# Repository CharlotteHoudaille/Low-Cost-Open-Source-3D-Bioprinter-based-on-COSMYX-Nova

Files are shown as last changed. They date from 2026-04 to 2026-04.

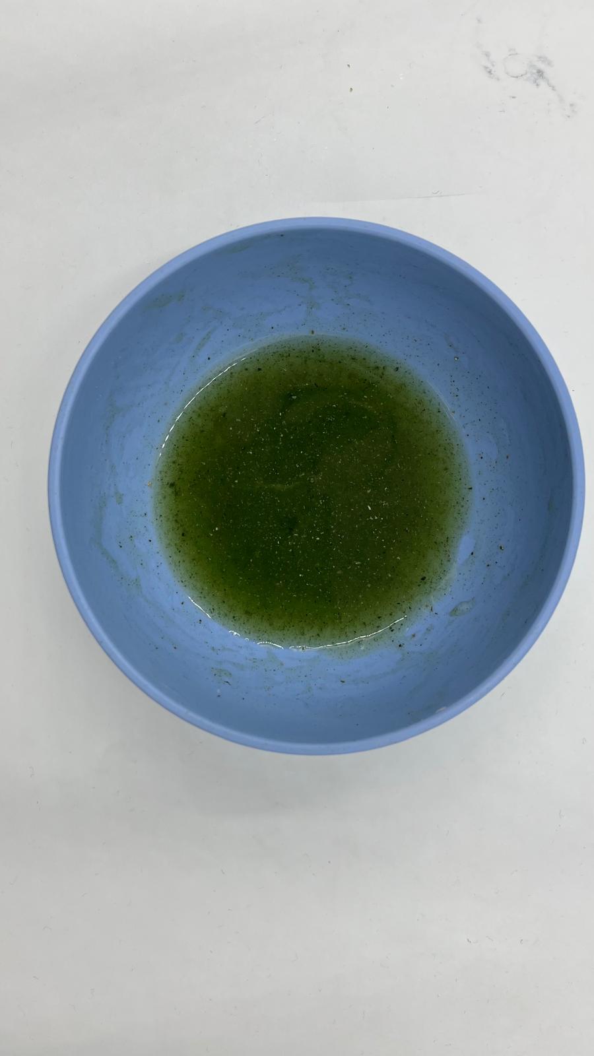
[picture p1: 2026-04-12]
test_hydrogels/spirulina/spiruina_preparation.jpeg

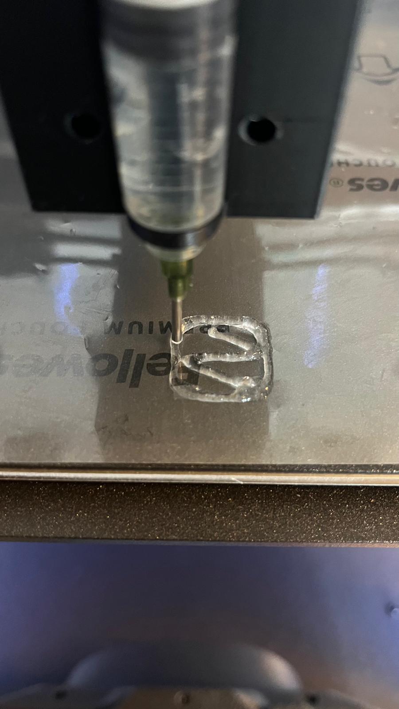
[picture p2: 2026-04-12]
test_hydrogels/cmc_alginate/print_tests/print2.jpeg

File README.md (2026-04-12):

# Low-Cost Open-Source 3D Bioprinter based on COSMYX Nova

## Project Overview
This project explores the transformation of a conventional **FDM 3D printer (COSMYX Nova)** into a **low-cost syringe-based bioprinter** capable of printing hydrogels and bio-derived materials.

The objective is to make bioprinting technologies more accessible to **open-source, DIY, and low-budget research communities**.

The project covers:
- custom hardware modification
- firmware and machine debugging
- slicer calibration
- hydrogel testing
- biological material experiments
- future hardware and research improvements

---

## Project Goals
- convert a standard 3D printer into a syringe-based bioprinter
- print extrusion-based hydrogels
- test bio-derived materials such as spirulina
- document a reproducible low-cost setup

---

## Repository Structure

### `/hardware`
Contains all mechanical documentation related to the custom print head:
- CAD files
- STL / fabrication files
- assembly guide
- hardware description
- print head architecture

---

### `/firmware`
Contains all software and machine configuration documentation:
- OctoPrint / Klipper setup
- firmware modifications
- temperature override
- bed mesh correction
- SD card reflashing and debugging notes

---

### `/slicer`
Contains the slicing workflow and calibration files:
- Orca Slicer project file (`.3mf`)
- calibration parameters
- printing methodology
- key parameters for hydrogel extrusion

---

### `/test_hydrogels`
Contains all hydrogel formulations and print tests:
- CMC–alginate recipe and results
- spirulina hydrogel recipe and results
- photos and videos of gels and printed structures
- experimental observations

---

## System Summary
The original thermoplastic extruder was replaced by a **custom syringe extrusion system**.

The existing stepper motor drives:
- a gear train
- a vertical screw mechanism
- a syringe holder / piston pusher

This allows controlled extrusion of high-viscosity hydrogels.

---

## Main Experimental Results
The project successfully demonstrated:
- 2D hydrogel printing
- 3D hollow and filled structures
- proof-of-concept extrusion of spirulina-based material
- iterative firmware and slicer calibration

This work does **not yet constitute a full viability study**, but demonstrates the feasibility of low-cost hydrogel bioprinting.

---

## Future Contributions
Potential future developments include:
- improved lead screw mechanism
- stronger syringe guidance system
- better linear alignment
- enhanced firmware robustness
- plastic upcycling / filament recycling project

---

## Author
Charlotte Houdaille  
CreaTech IFT – ESILV# Low-Cost-Open-Source-3D-Bioprinter-based-on-COSMYX-Nova
## Project Overview
This project explores the transformation of a conventional FDM 3D printer (COSMYX Nova) into a low-cost extrusion-based bioprinter capable of printing hydrogels and bio-derived materials. The objective is to make bioprinting technologies accessible to open-source and DIY research communities.

This work includes:
- hardware modification of the printer
- firmware and software debugging
- slicer calibration
- test hydrogel formulation
- biological material experiment
- hardware improvements

---

## Project Goals
- Transform a standard 3D printer into a syringe-based bioprinter
- Print extrusion-based hydrogels
- Test biologically derived materials such as spirulina
- Document a reproducible low-cost setup

---

## System Architecture

### Hardware
The original FDM extruder was replaced by a **custom syringe extrusion system**.

The printer’s original stepper motor drives:
- a gear train
- a central screw
- a moving white carriage (syringe holder to control extrusion flow)

### Main Components
- COSMYX Nova 3D printer
- custom 3D-printed syringe holder
- custom 3D-printed gear mechanism
- vertical screw
- syringe + nozzle

---

## Hardware Documentation

### Bill of Materials (BOM)
- COSMYX Nova printer
- stepper motor (existing printer motor)
- 3D-printed gears
- screw
- syringe holder
- syringe piston pusher
- 20 mL syringe
- nozzle
- screws and mounting parts
- Raspberry Pi
- SD card

Detailed BOM available in `/hardware/BOM_hardware.md`
The 3D files for the different parts of the printhead can be found in the hardware branch.
Please note that the full assembly also requires M8 nuts and bolts, along with two aluminum support rods (8.30 mm diameter) with lengths of 106.5 mm and 74.50 mm, which must be inserted into the syringeholder part.

---

## Assembly Instructions
1. Remove the original thermoplastic extruder
2. Install the syringe holder on the carriage
3. Mount the gear system
4. Connect the stepper motor to the gears
5. Install the threaded rod
6. Attach the piston pusher mechanism
7. Insert the syringe
8. Test vertical movement
9. Validate extrusion motion

Detailed assembly guide available in `/hardware/assembly_guide.md`

---

## Software / Firmware

### Firmware Stack
- OctoPrint
- Klipper
- Raspberry Pi

### Debugging Performed
During the project, several firmware issues had to be resolved:
- emergency stop causing display failure
- SD card reflashing
- Raspberry Pi software update
- nozzle and bed unwanted heating
- bed mesh collision issues
- chassis collision correction

Configuration notes available in `/firmware`

---

## Slicer Calibration
The project required adapting standard FDM slicing workflows to hydrogel extrusion.

Software used:
- **Orca Slicer**

Main parameters calibrated:
- layer height
- extrusion flow
- infill density
- speed
- line width
- temperature disabled
- multi-layer stacking

Calibration tests included:
- 2D heart shape
- hollow cube
- filled cube

Files and notes available in `/slicer`

---

## Materials / Hydrogel Formulations

### CMC + Alginate Hydrogel
- 40 mL distilled water
- 2 g alginate
- 2 g carboxymethylcellulose

Used for calibration and structural print tests.

---

### Spirulina Hydrogel
- 40 mL distilled water
- 5 g spirulina
- 2 g alginate
- 2 g glycerol

Crosslinked in calcium chloride bath.

Detailed formulations available in `/materials`

---

## Experimental Results

### Calibration
Several iterative print-calibration loops were carried out:
1. modify Orca Slicer parameters
2. test print
3. observe results
4. repeat

This allowed progressive improvement of:
- line consistency
- layer stacking
- 3D print fidelity

---

### Biological Material Test
A spirulina-based hydrogel was successfully extruded as a proof of concept of **bio-derived material printing**.

This stage focused on:
- extrusion feasibility
- shape retention
- hydrogel stability

This is **not yet a proof of biological viability study**.

---

## Applied Research
Inspired by the *LivingLoom* paper (CHI 2025), a methodology based on:
- hydrogel formulation
- crosslinking bath
- washing phase
- growth observation over time

was partially replicated to explore post-fabrication biological development.

---

## Images / Demo
Project photos, screenshots and demo results are available in:

- `/images/demo_photos`
- `/images/calibration_tests`
- `/images/spirulina_tests`
- `/videos`

---

## Future Contributions
- improved lead screw mechanism
- stronger syringe holder
- better linear guidance
- improved firmware robustness
- integration on Prusa platform
- plastic upcycling line (Ghana project)

---

## References
See `/docs/references.md`

---

## Author
Charlotte Houdaille  
CreaTech – ESILV

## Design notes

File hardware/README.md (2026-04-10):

# Print Head / Extrusion System

The design of the extrusion head was initially inspired by previous work from **Cordova et al. – The Enderstruder**.

Unlike many commercial bioprinters that rely on pneumatic pumping systems, this project uses a **piston-based extrusion mechanism**. Pneumatic systems require very precise pressure control and can make bio-ink retention during printing more difficult.

For this reason, we chose a **mechanical piston extrusion system** driven by the existing motor of the COSMYX Nova printer.

The system includes a **1:4 gear ratio transmission**, designed to increase torque and allow the extrusion of **high-viscosity hydrogels and bio-inks**.

The printer’s original stepper motor drives the gear train, which rotates a central screw mechanism. This causes the piston carriage to move vertically and apply controlled pressure to the syringe plunger.

Initial iterations were based on the original vertical design proposed in the Enderstruder model.

However, due to the specific geometric constraints of the **COSMYX Nova architecture**, a complete redesign of the print head was required.

Several design iterations were carried out in order to optimize:
- alignment
- rigidity
- syringe stability
- collision avoidance with the frame

The final version corresponds to the design used for the calibration and hydrogel printing experiments.

---

## CAD Files

All 3D fabrication files are available in:

`hardware/cad_files/`

This folder includes the different mechanical parts of the extrusion system, such as:

- core structure
- syringe holder
- piston
- bevel gears
- herringbone gears
- sensor holder

The complete assembly also requires:
- M8 screws and nuts
- two aluminium support rods
- syringe and nozzle

---

## Assembly Guide

A detailed assembly and disassembly guide is available in:

`hardware/Montage Guide.pdf`

This document explains how to:
- remove the original FDM extruder
- install the custom syringe extrusion system
- mount the gears and piston
- insert the support rods
- assemble the syringe holder

---

## Installation Notes

Before installing the extrusion head, the original FDM extruder must be fully removed in order to free the support plate.

Once the original extruder is removed, follow the **Montage Guide.pdf** for the complete assembly process.

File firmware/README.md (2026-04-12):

# Firmware and Machine Configuration

This folder documents the firmware modifications performed on the COSMYX bioprinter.

The printer runs on **OctoPrint + Klipper**.

A significant part of the project involved debugging and modifying the machine configuration in order to adapt the printer to the custom syringe extrusion system.

---

## Main Firmware Modifications

### 1. Temperature Control Override
For hydrogel printing, nozzle and bed heating had to be completely disabled.

The original printer firmware was still forcing temperature control even when disabled in Orca Slicer.

To solve this, several temperature-related parameters were manually modified in the Klipper configuration files.

Key changes include:
- nozzle temperature set to 0
- bed temperature set to 0
- home preheat variables disabled
- minimum extrusion temperature reduced

See:
- `temperature_override_parameters.png`

---

### 2. Extruder Parameters
The custom syringe extrusion system required modifications to the default extruder settings.

Main modified parameters include:
- rotation distance
- nozzle diameter
- minimum extrusion temperature
- max extrusion cross-section

These changes were necessary to adapt the printer to **hydrogel syringe extrusion instead of thermoplastic filament extrusion**.

See:
- `extruder_configuration_parameters.png`

---

### 3. Bed Mesh Correction
Because the custom syringe extruder is significantly larger than the original FDM extruder, the default bed mesh area was causing collisions with the frame.

The `[bed_mesh]` parameters were modified in order to reduce the probing zone and avoid the custom print head hitting the chassis.

Main modified parameters include:
- mesh_min
- mesh_max
- horizontal_move_z
- probe_count

See:
- `bed_mesh_parameters.png`

---

## Configuration File Location
All these parameters were modified through:

**OctoPrint → Klipper Configuration → Config Files**

See:
- `klipper_config_files_overview.png`

---

## Major Debugging Incident
During the calibration phase, a major issue occurred after an emergency stop had been triggered earlier in January.

This caused the printer screen to stop displaying anything.

To recover the system, the following steps were performed:
- opening the printer electronics
- locating the Raspberry Pi
- removing the SD card
- reflashing the SD card with a fresh image
- reinstalling OctoPrint / Klipper configuration

This debugging phase was essential to restore the machine and continue the calibration work.

---

## Important Note
These firmware modifications are **specific to the custom syringe extrusion system** and should not be used for standard FDM printing without verification.

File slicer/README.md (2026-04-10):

# Slicer Documentation

This folder contains the slicing setup used during the hydrogel calibration and 3D printing tests.

The main project file is:

`cmc_alginate_calibration.3mf`

This file already contains all the calibrated Orca Slicer parameters used for the **CMC–alginate hydrogel**.

The full hydrogel recipe can be found in the **Hydrogels** section of the main repository documentation.

---

## Important Note

All the slicing parameters saved in the `.3mf` file were specifically optimized for the **CMC–alginate hydrogel formulation**.

These settings are **not intended for standard thermoplastic printing**.

The calibration was developed for:
- syringe extrusion
- high-viscosity hydrogel flow
- stable layer stacking
- filled 3D structures

---

## Key Parameters

Some of the most important parameters adjusted during the calibration process include:

### Layer Height
Example:
- layer height: **1 mm**
- initial layer height: **1 mm**

A larger layer height was required to match the extrusion flow of the hydrogel.

---

### Line Width
Example:
- default line width: **1.2 mm**
- outer wall: **1.2 mm**
- infill: **1.2 mm**

The line width was increased to improve:
- line continuity
- wall stability
- infill cohesion

---

### Infill
The infill settings were one of the most critical parameters to tune.

Several iterations were performed to obtain:
- filled cubes
- stable internal structure
- good contact between walls and infill

---

### Speed
Printing speed was progressively reduced in order to improve hydrogel deposition and avoid flow inconsistencies.

---

### Temperature
Nozzle and bed heating were disabled for hydrogel printing.

---

## Calibration Workflow
The calibration followed an iterative loop:

1. modify one parameter
2. print test geometry
3. observe result
4. adjust settings
5. repeat

This was repeated multiple times on:
- 2D heart
- hollow cube
- filled cube

---

## Recommendation
For any new hydrogel formulation, the following parameters should be adjusted first:

- layer height
- line width
- print speed
- infill density
- flow consistency

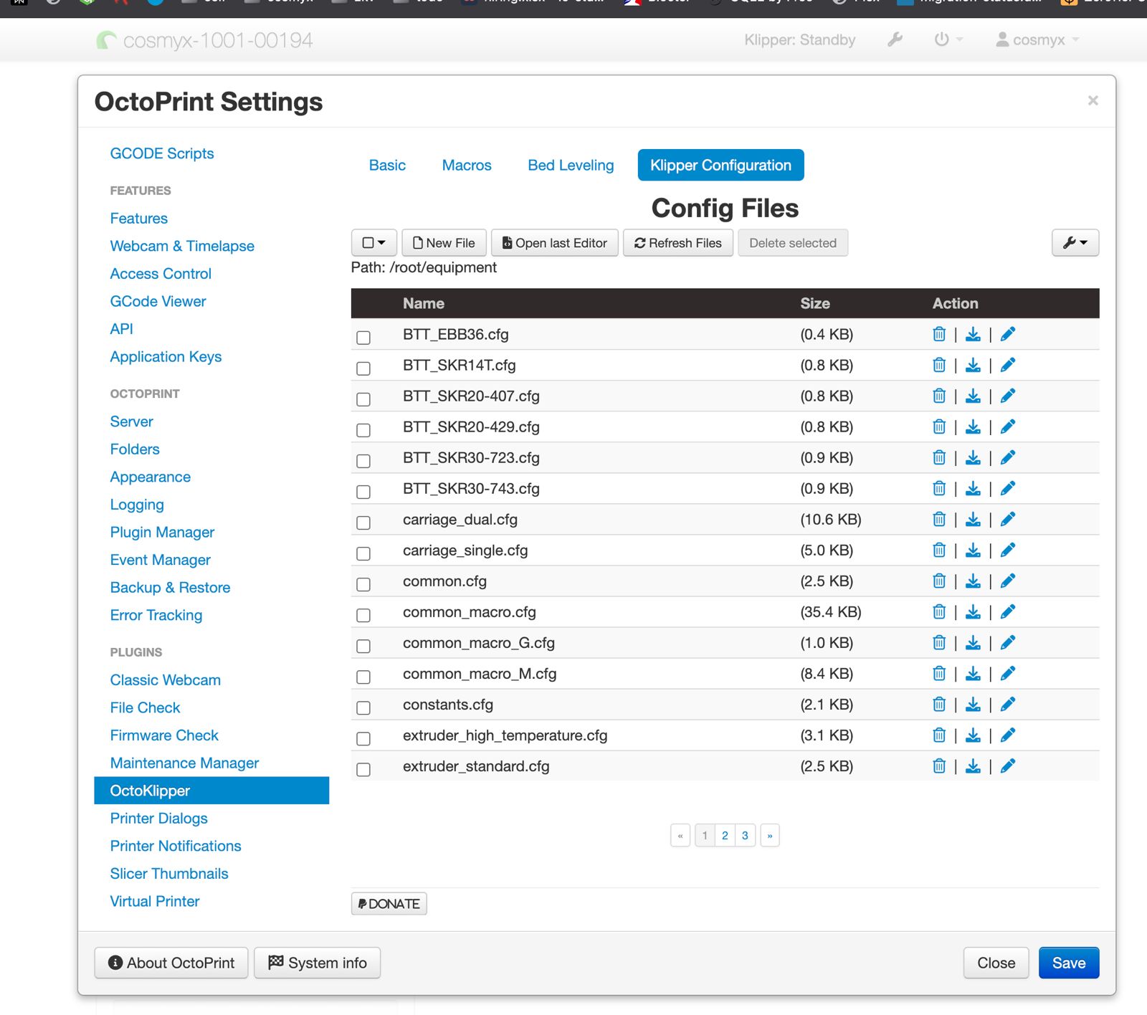
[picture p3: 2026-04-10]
firmware/screenshots/ klipper_config_files_overview.png

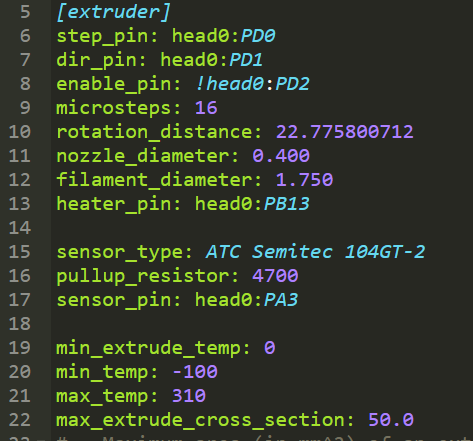
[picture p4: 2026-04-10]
firmware/screenshots/extruder_configuration_parameters.png

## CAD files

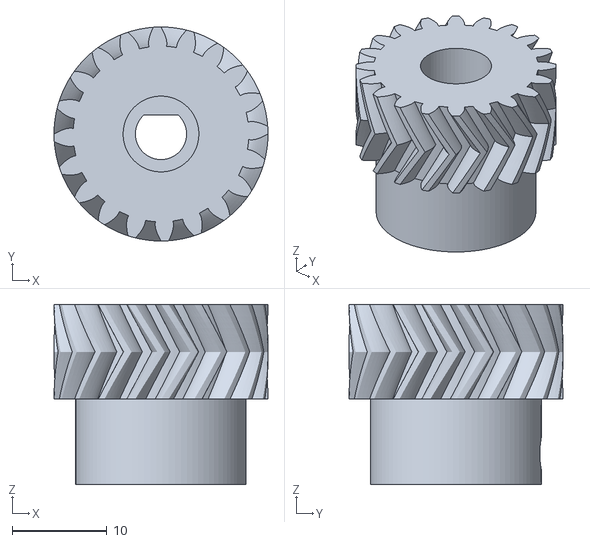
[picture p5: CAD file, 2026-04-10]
hardware/cad_files/Small herringbone gear.stl
22.6 x 22.6 x 19.0

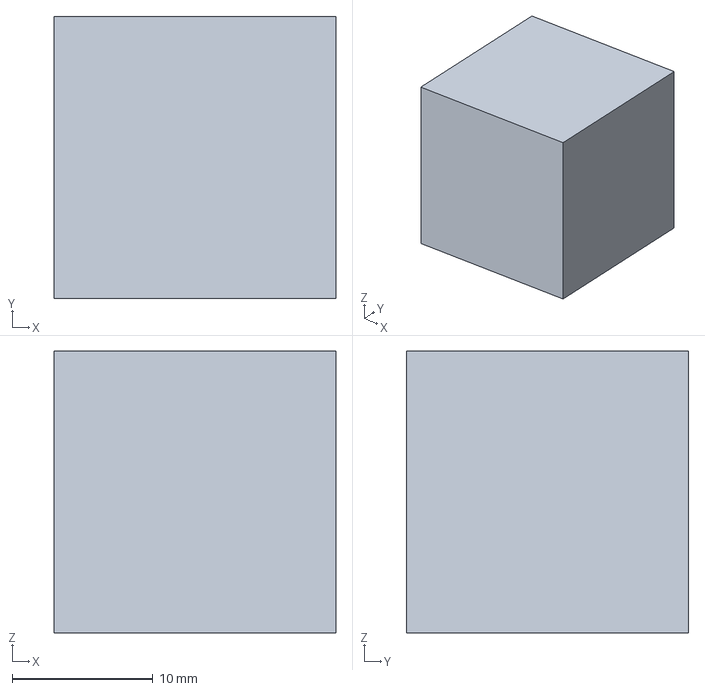
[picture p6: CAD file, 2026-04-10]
slicer/cmc_alginate_calibration.3mf
20.0 x 20.0 x 20.0 mm

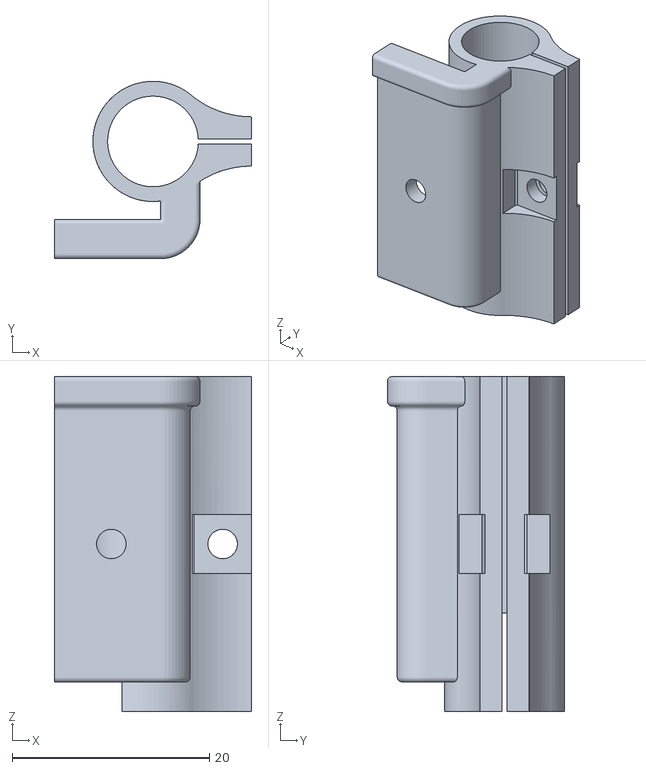
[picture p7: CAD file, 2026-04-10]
hardware/cad_files/sensor.stl
20.0 x 18.0 x 34.0

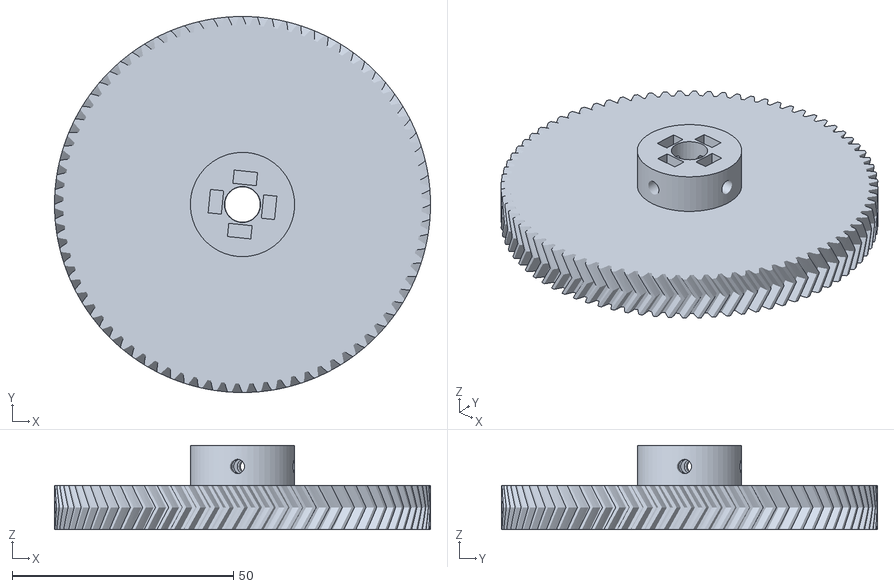
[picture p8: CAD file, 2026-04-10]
hardware/cad_files/Large herringbone gear.stl
84.9 x 84.9 x 19.0

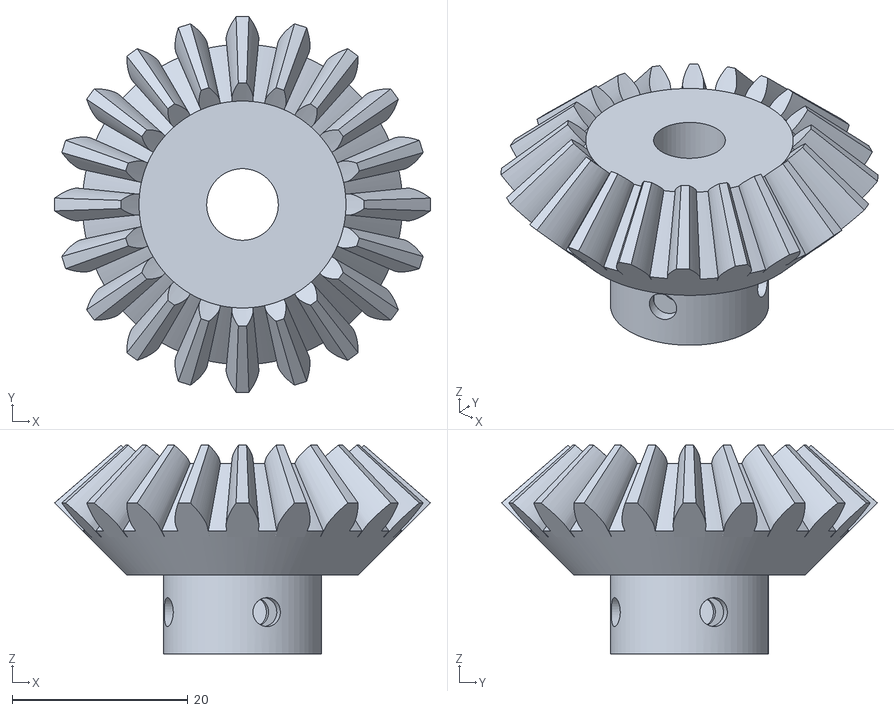
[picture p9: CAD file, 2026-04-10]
hardware/cad_files/bevel gear_29.stl
42.8 x 42.8 x 23.8

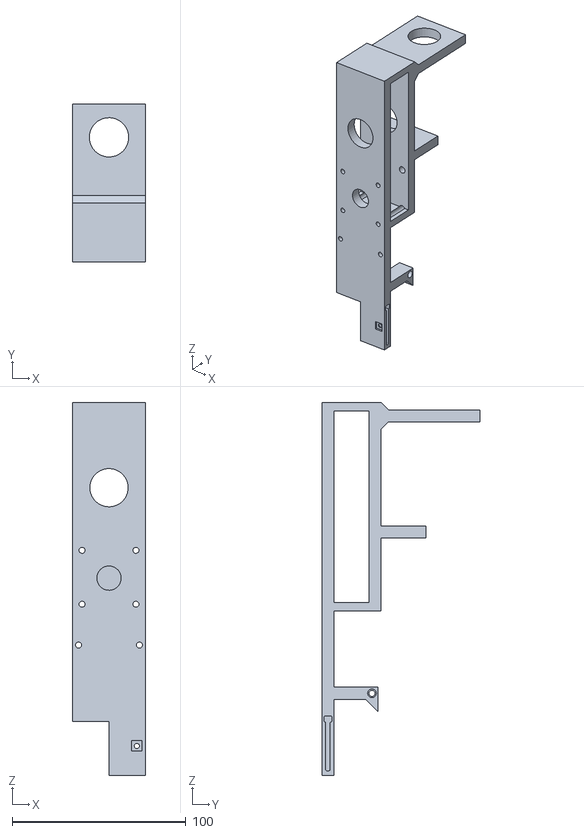
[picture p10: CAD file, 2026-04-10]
hardware/cad_files/core.stl
42.0 x 91.0 x 214.5

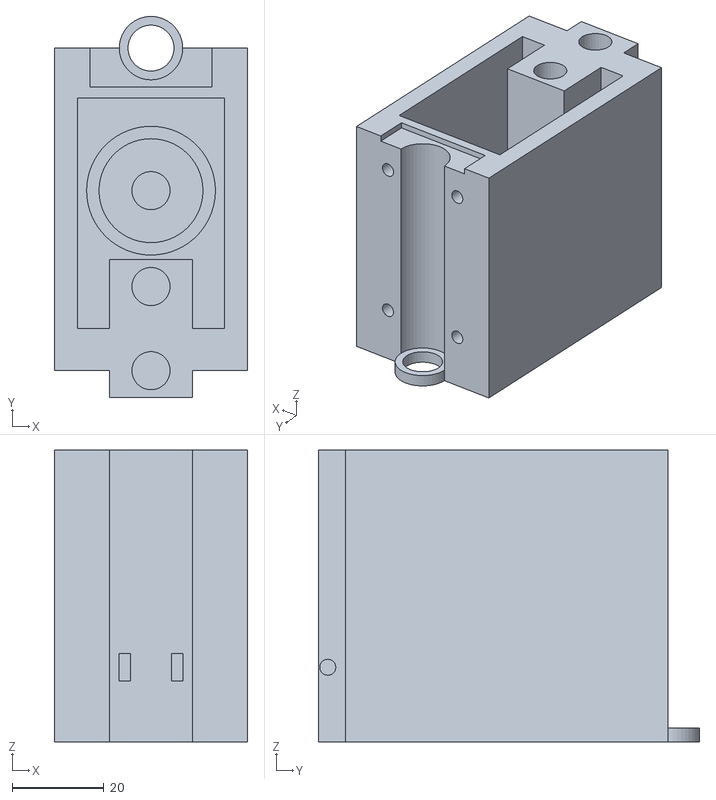
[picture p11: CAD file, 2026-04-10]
hardware/cad_files/syringeholder.stl
42.0 x 82.9 x 63.5

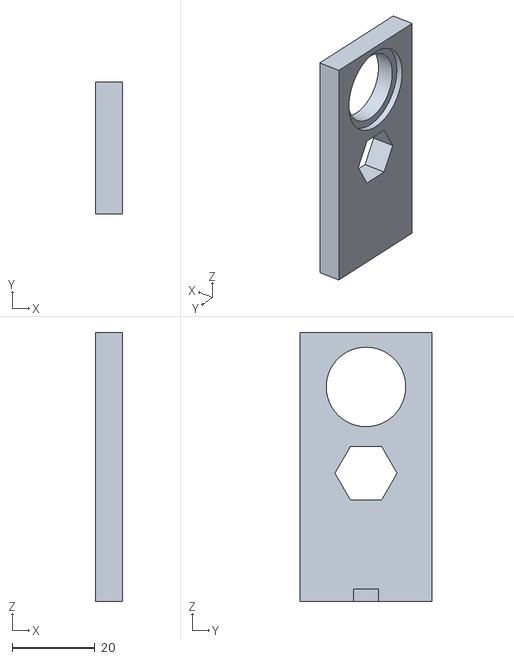
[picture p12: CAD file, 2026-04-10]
hardware/cad_files/Piston.stl
6.50 x 32.0 x 65.0

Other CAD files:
hardware/cad_files/bevel gear_28.stl

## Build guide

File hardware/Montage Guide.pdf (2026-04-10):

Guide de Montage/démontage tête de bio impression Cosmyx Nova

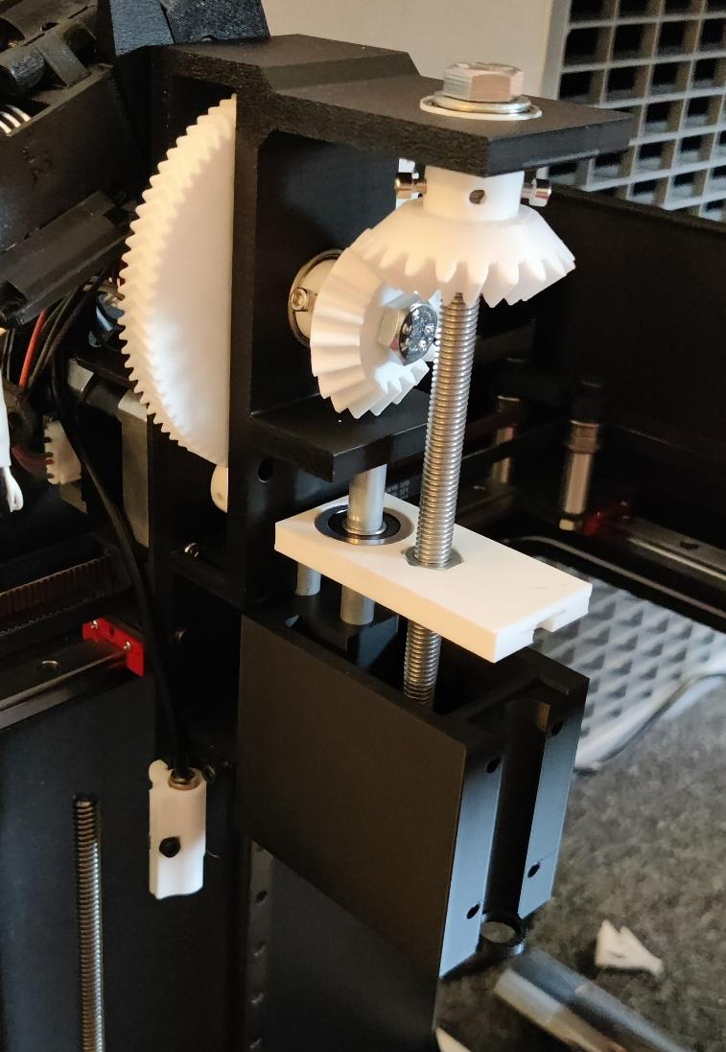
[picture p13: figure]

Démontage
1- Eteindre l’imprimante & retirer la seringue
2- Dévisser le porte seringue et retirer le module par le bas

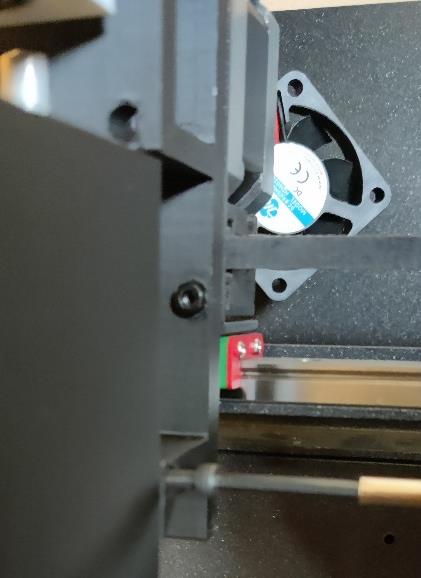
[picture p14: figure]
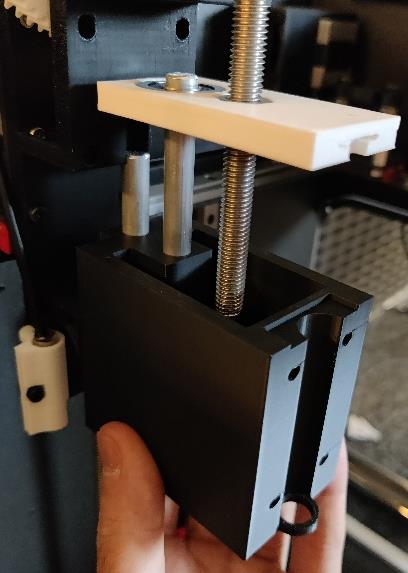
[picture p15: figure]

3- Sur le grand axe de rotation, dévisser

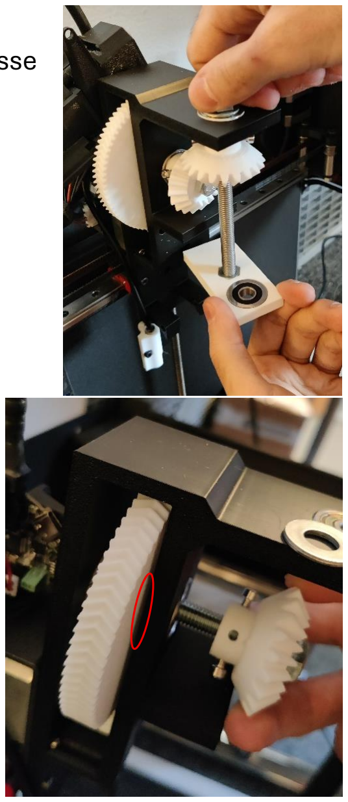
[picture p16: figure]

l’engrenage conique, puis dévisser le presse seringue.
Enfin retirer l’axe entièrement.

4- Sur l’axe restant, dévisser le grand engrenage et retirer l’axe, attention à la rondelle (marquée par un cercle rouge)

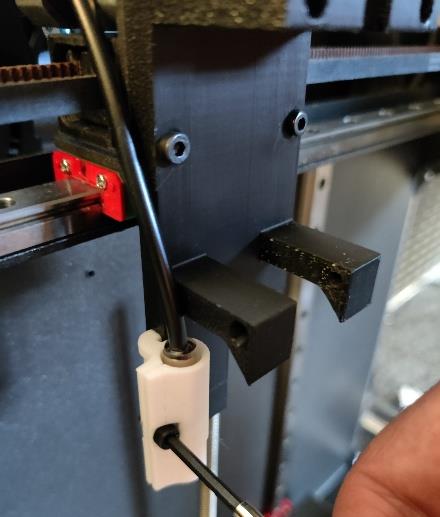
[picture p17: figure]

5- Retirer le capteur de hauteur (pour éviter de tirer sur le fil. Optionnellement, garder le composant attaché mais débranché)

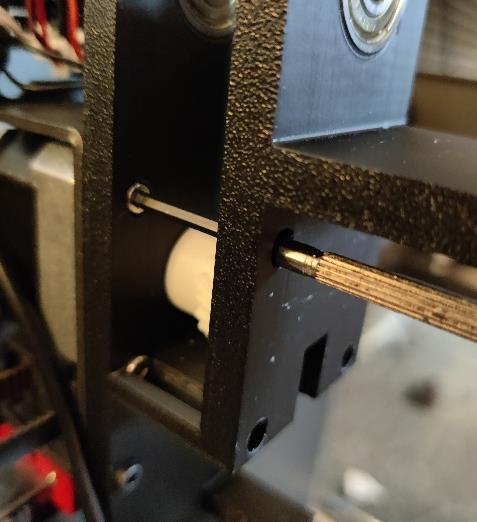
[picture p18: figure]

6- Retirer les 6 vis restantes à la base de la tête, puis tirer pour retirer l’ensemble avec le petit engrenage

Montage
1- Enfoncer la base de la tête avec le petit engrenage. Puis visser 2- Installer le capteur de hauteur (mettre le capteur dans le module avant de visser le module)
3- Installer le petit axe de rotation avec leurs engrenages
4- Installer le porte seringue
5- Installer le presse-seringue et le second engrenage conique avec le grand axe de rotation.

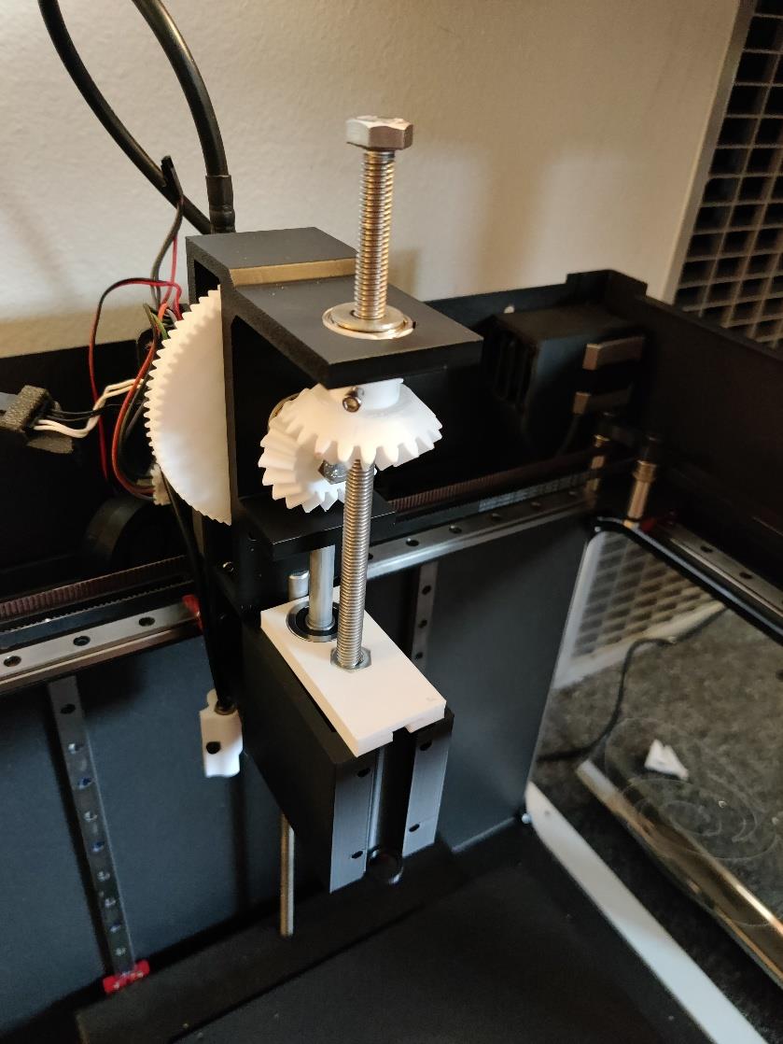
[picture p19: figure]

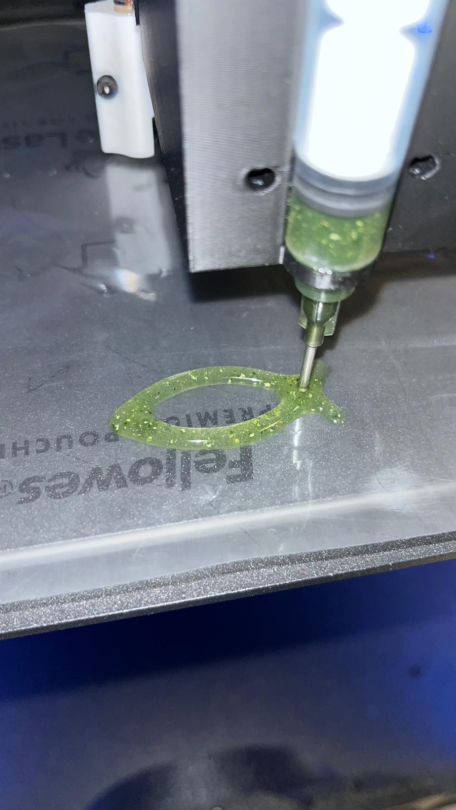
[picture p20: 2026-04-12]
test_hydrogels/spirulina/prints/print6.jpeg

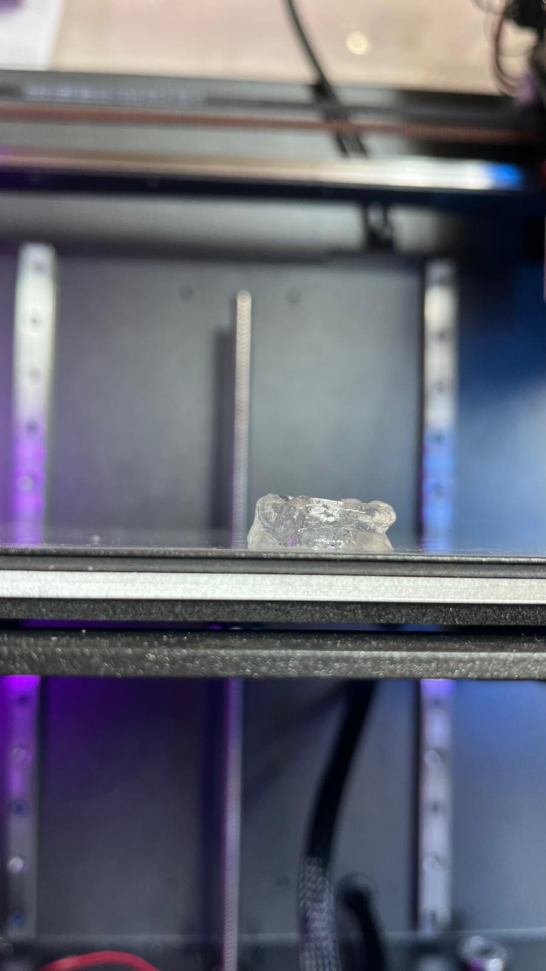
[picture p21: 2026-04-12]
test_hydrogels/cmc_alginate/print_tests/print1.jpeg

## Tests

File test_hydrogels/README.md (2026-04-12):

# Hydrogel Testing

This folder documents the different hydrogel formulations tested during the project, along with their print results.

Each formulation includes:
- recipe
- preparation notes
- photos of the hydrogel
- print tests
- videos of extrusion results

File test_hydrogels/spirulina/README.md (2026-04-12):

# Spirulina Hydrogel

## Recipe
- 40 mL distilled water
- 5 g spirulina biomass
- 2 g sodium alginate
- 2 g glycerol

## Objective
This formulation was used as a proof of concept for printing bio-derived materials.

## Notes
The objective was not to demonstrate viability, but successful extrusion and shape retention.

See attached photos and videos for results.

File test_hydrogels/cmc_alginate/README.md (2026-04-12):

# CMC–Alginate Hydrogel

## Recipe
For 100mL
- 3 wt% CMC in distilled water 80mL (vigorous stirring).
- 2 wt% alginate 
- 5 wt% glycerol 
1–2 h hydration before printing.
Calcium chloride bath 2 wt%

## Use
This formulation was used for slicer calibration.

## Notes
This hydrogel provided the best balance between viscosity and printability during the calibration phase.

See attached images and videos for printing results.

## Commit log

2026-04-12 Rename Capture d'écran 2026-03-30 195139.png to in common.cfg
    [in common.cfg]
2026-04-12 Rename Capture d'écran 2026-03-30 195338.png to in extruder_standard.cfg
    [in extruder_standard.cfg]
2026-04-12 Rename Capture d'écran 2026-03-30 195246.png to in constants.cfg
    [in constants.cfg]
2026-04-12 Rename files in OctoPrint to klipper_config_files_overview.png
2026-04-12 Rename in constants.cfg to temperature_override_parameters.png
2026-04-12 Rename in extruder_standard.cfg to extruder_configuration_parameters.png
2026-04-12 Rename WhatsApp Image 2026-03-29 at 10.10.30 PM.jpeg to custom syringe extruder
2026-04-12 Create print_tests
2026-04-12 Create prints
